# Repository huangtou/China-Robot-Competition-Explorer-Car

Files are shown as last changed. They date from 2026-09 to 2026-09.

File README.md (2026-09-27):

# TianXian · 车型探险机器人

> 主控 STM32F407ZGT6 + MaixCam 视觉，四轮底盘，完成「巡线 → 越障/过桥 → 识别景点数字 → 语音播报 → 返程」全流程的竞赛机器人开源工程。
>
> 包含：STM32 固件（HAL 库 + Keil 工程）、视觉模型与部署脚本、机械结构（SolidWorks）、PCB（立创 EDA）。

<p align="center">
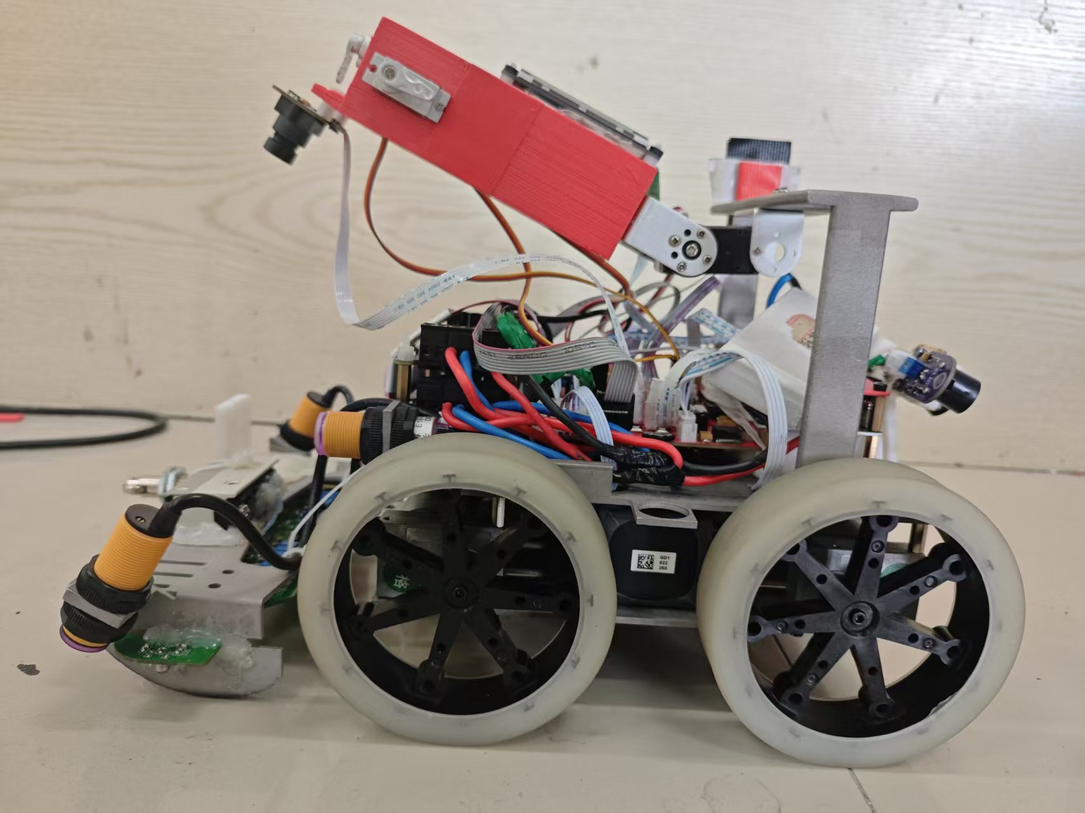
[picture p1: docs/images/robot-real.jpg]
整车实物
  
  <br>
  <em>整车实物</em>
</p>

| 机械结构（3D 预览） | 主控 PCB（3D 预览） |
| :---: | :---: |
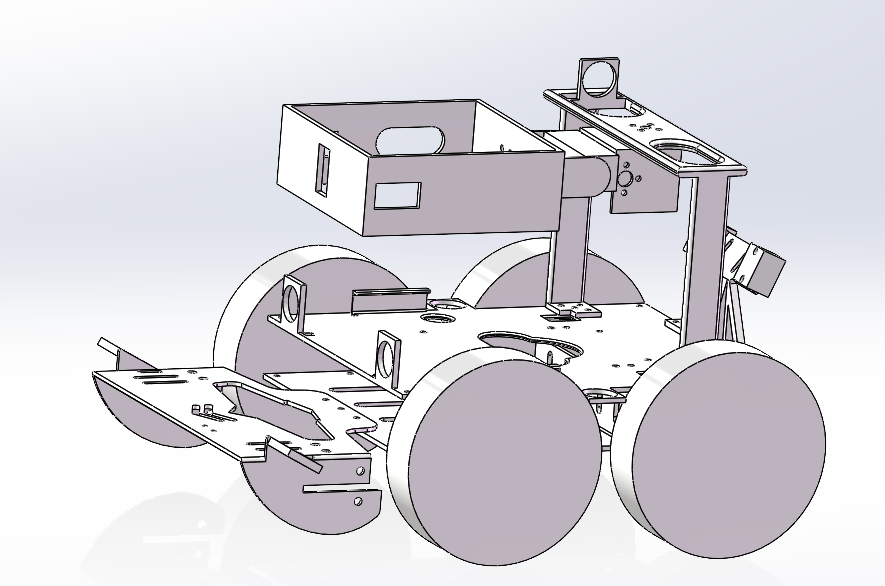
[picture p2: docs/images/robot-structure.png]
机械结构
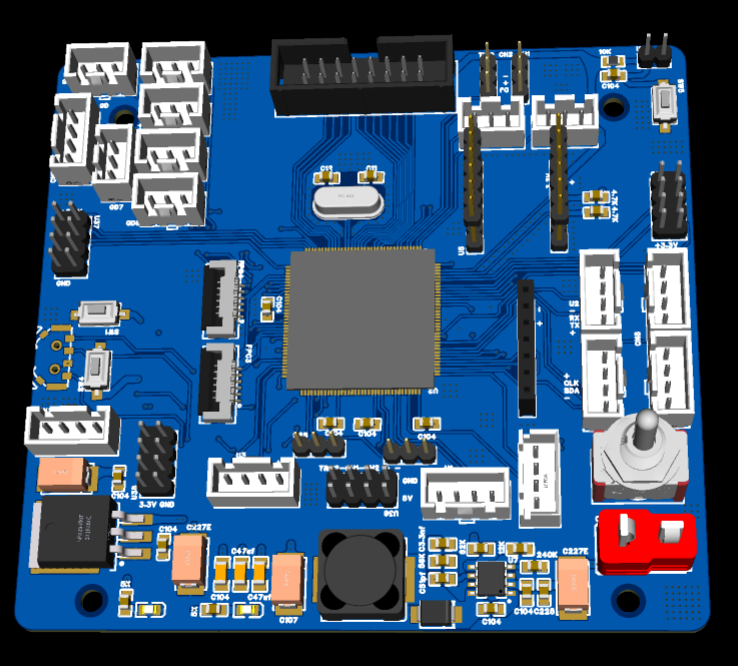
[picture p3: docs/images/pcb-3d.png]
主控 PCB
|  |  |

**[▶ 演示视频（Bilibili，V1）](https://www.bilibili.com/video/BV1UiGg6rEV1/)**

---

## 一、项目简介

机器人以「五岳景点打卡」为任务背景：沿场地循迹行进，途中完成上/下阶梯、过桥、上下平台等动作，用摄像头识别景点编号（1~5），通过语音模块播报「到达东岳泰山 / 西岳华山 / 南岳衡山 / 北岳恒山 / 中岳嵩山」，最后回到起点。

- **主控**：STM32F407ZGT6（LQFP144，168 MHz）
- **底盘**：4 × 带编码器减速电机（四轮独立速度闭环）
- **视觉**：MaixCam 运行 YOLOv5（224×224，5 类），UART 回传识别结果
- **导航**：12 路灰度 + 2 路线性 CCD 巡线，HWT101 陀螺仪航向闭环，光电/激光/微动开关做定位与触发
- **交互**：TJC 串口屏菜单选模式、SYN6288 语音播报、VOFA+ 上位机调参

## 二、功能特性

| 能力 | 实现 |
| --- | --- |
| 巡线 | 12 路灰度 `Huidu_findline` + 2 路线性 CCD `CcdFindLine2`，分段 PID（按速度切换 5 套参数） |
| 运动控制 | 4 路电机速度环 PID（`htim6` 1 ms 中断）+ 编码器里程计 + 陀螺仪角度环 PID |
| 动作原语 | `go / go_enco / go_time / go_GD / go_acc / HWT101_go / HWT101_go_rotate` 等，支持自定义终止回调 |
| 任务编排 | `part1_pro ~ part4_pro` 四段路线，配合 `flagroad_0~4` 岔路标记位 |
| 视觉识别 | MaixCam YOLOv5 数字识别，稳定 4 帧后才发送，超时自动复 0 |
| 语音播报 | SYN6288 合成播报，首次识别结果缓存至 `ZL[5]`，二次经过直接复播 |
| 调试工具 | 串口屏菜单 16 种模式、VOFA+ 实时波形、`keilkill.bat` 清理编译中间产物 |

## 三、目录结构

```
.
├── 代码/stm32代码HAL库/
│   ├── Core/                 # CubeMX 生成的时钟/外设初始化与 main.c
│   ├── Drivers/              # STM32F4 HAL 库、CMSIS
│   ├── Hard-and-Software/    # 本项目全部应用层代码（见下表）
│   ├── MDK-ARM/              # Keil uVision 工程（TianXian.uvprojx）
│   ├── Camera/               # MaixCam 视觉应用与模型
│   │   ├── 2.0-es/           # 早期模型 316024
│   │   ├── 2.2-es/           # 模型 316110
│   │   └── 2.3/              # 推荐版本：2.0-es 逻辑 + 316110 模型
│   ├── TianXian.ioc          # STM32CubeMX 配置（外设/引脚/时钟）
│   └── keilkill.bat          # 清理 Keil 编译中间文件
├── 结构/                      # SolidWorks 零件与装配体（.SLDPRT/.SLDASM/STL）
├── PCB/
│   └── PCB.eprj2             # 立创 EDA 专业版工程
├── docs/images/              # README 用预览图（整车实物、机械结构、PCB 3D 渲染）
└── README.md
```

### 应用层模块（`Hard-and-Software/`）

| 文件 | 职责 |
| --- | --- |
| `sys.c/h` | 全局头文件聚合、`CAR_STRUCT` 车体状态结构体、`Para_Init` 参数初始化 |
| `move.c/h` | 电机 PWM 输出、编码器/速度采集、速度环与角度环 PID |
| `base.c/h` | 运动原语：定距、定时、加速、灰度终止、陀螺仪转向等 |
| `private.c/h` | 任务流程：`Ready / LBridge / to5 / gohome` 等，以及 `part1~4_pro` |
| `Huidu.c/h` | 12 路灰度寻线偏差计算 |
| `CCD.c/h` | 线性 CCD 时序驱动、自动曝光、寻线与 CCD 巡线 PID |
| `HWT101.c/h` | 软件 I²C 读取 HWT101 陀螺仪、角度标定 |
| `Kalman.c/h` | 传感器数据卡尔曼滤波 |
| `GD.c/h` | 光电/激光/微动开关等数字量输入 |
| `HSL.c/h` | 颜色传感器（软件 I²C） |
| `DJ.c/h` | 舵机动作组：身体、摄像头云台、左右手 |
| `myusart.c/h` | printf 重定向、MaixCam 协议解析、SYN6288 语音帧组包 |
| `Serial.c/h` | `Serial.HMI`（串口屏）/ `Serial.Vofa`（VOFA+）格式化输出 |
| `key.c/h` | 按键扫描与运行模式选择 |
| `Timer.c/h` | 定时器中断回调（控制 / 采集 / 计时） |

## 四、硬件与引脚分配

| 外设 | 引脚 / 资源 | 说明 |
| --- | --- | --- |
| 电机 PWM | TIM4 CH1~CH4（轮 1/2）、TIM5 CH1~CH4（轮 3/4） | 每轮两路 PWM 实现正反转 |
| 编码器 | TIM1 / TIM2 / TIM3 / TIM8（编码器模式） | 4 路 AB 相 |
| 舵机 | TIM9 CH1/CH2（身体、云台）、TIM12 CH1/CH2（右手、左手） | 50 Hz |
| 灰度传感器 | ADC3 + DMA2_Stream0，12 通道扫描 | `AD_value[12]` |
| 线性 CCD ×2 | CCD1：CLK=PG0、SI=PG1；CCD2：CLK=PE7、SI=PE8；ADC2 CH4/CH5 | TSL1401 类 128 像素 |
| 陀螺仪 HWT101 | 软件 I²C：SDA=PE0、SCL=PE1 | 航向角闭环 |
| 颜色传感器 HSL | SDA=PD2、SCL=PD3 | |
| 光电开关 | GD1=PA6、GD2=PA7、GD5=PC4、GD6=PC5、GD7=PB0、GD8=PB1 | 定位/计数 |
| 激光对射 | JG1=PE2、JG2=PE3 | |
| 微动开关 | QC1=PC13 | 到位检测 |
| 按键 ×4 | KEY_LEFT=PD8、KEY_MID=PD9、KEY_RIGHT=PD10、KEY1=PD11 | 模式选择 |
| USART1 | PA9/PA10 | TJC 串口屏 + `printf` 重定向 |
| USART2 | PD5/PD6 | MaixCam 数据接收（RX）+ VOFA+（TX），115200 |
| USART3 | PB10/PB11 | SYN6288 语音合成模块 |
| 定时器 | TIM6 控制（1 ms）、TIM7 采集（1 ms）、TIM10 计时 | |

## 五、编译与烧录

1. **环境**
   - Keil MDK-ARM **V5.32** 及以上，安装 STM32F4 器件支持包
   - STM32CubeMX（本项目基于 `STM32Cube FW_F4 V1.28.1` 生成）
2. 打开 `代码/stm32代码HAL库/MDK-ARM/TianXian.uvprojx`，编译（Target: TianXian）后通过 ST-Link 下载。
3. 修改外设配置时用 CubeMX 打开 `TianXian.ioc` 重新生成即可（用户代码写在 `USER CODE BEGIN/END` 之间，不会被覆盖）。
4. 提交仓库前建议运行 `keilkill.bat` 清理 `Objects/`、`Listings/` 等中间文件。

## 六、视觉模型部署（MaixCam）

1. 将 `Camera/2.3/` 下 `app.yaml`、`main.py`、`app.png`、`model_316110.mud`（或 `.cvimodel`）、`report.json` 打包，在 [MaixHub](https://maixhub.com) 部署或直接用 MaixVision 安装到设备。
2. 模型：YOLOv5n 级检测模型，输入 224×224，5 类，验证集准确率 0.982（`report.json`）。
3. **通信协议**：串口 `/dev/ttyS0`，115200，帧格式 `0xAA + ASCII('0'~'5') + 0xBB`
   - `'1'~'5'` 对应 东岳泰山 / 西岳华山 / 南岳衡山 / 北岳恒山 / 中岳嵩山（注意模型类序为 `3,4,5,1,2`，代码已做映射）
   - `'0'` 表示未识别到目标
   - 连续 4 帧同一结果才发送，之后每 10 帧补发一次；连续 60 帧无目标则发送 `'0'`

> 需要重新训练模型时，在 MaixHub 上传标注数据集（5 类）即可，导出后替换 `model_*.mud` 并同步 `CLASS_TO_NUMBER`。

## 七、运行与调试

1. 上电后串口屏显示模式选择界面：`左/右` 键切换编号（1~16），`中` 键确认，`KEY1` 直接跳到模式 5。
2. 常用模式（`main.c` 中 `Function_Value`）：

| 模式 | 功能 |
| --- | --- |
| 1 | 完整跑图（part1→part4 执行两轮） |
| 2 | 单轮跑图 |
| 3 | 灰度 / CCD 巡线调试 |
| 4 | HWT101 陀螺仪 + 光电调试 |
| 5 | 综合调试：串口屏显示 + 摄像头读取 |
| 6 | 摄像头识别 + 语音播报测试 |
| 8 | 直行测试 |

3. 调参入口集中在 `sys.c` 的 `Para_Init()`（灰度阈值 `ADW[]`、多套巡线 PID、速度/角度 PID）与 `move.c` 的 PID 实现；实时波形用 VOFA+ 打开 USART2 对应串口查看。

## 八、机械与硬件

| 机械结构 | 主控 PCB |
| :---: | :---: |
| 机械结构 | 主控 PCB |

- `结构/`：`装配体2.SLDASM` 为整机装配，其余为车身、电机底盘、舵机支架、轮子、CCD 支架、喇叭等零件，另附 `升级版ccd.STL` 可直接 3D 打印。
- `PCB/PCB.eprj2`：立创 EDA 专业版工程，直接导入即可查看/打样。

## 九、演示视频

- **V1 完整流程演示**：<https://www.bilibili.com/video/BV1UiGg6rEV1/> ｜ BV 号 `BV1UiGg6rEV1`

## 十、开源协议

本项目采用 **MIT License**。第三方组件遵循各自许可证：

- `Drivers/` 下 STM32 HAL / CMSIS 遵循 ST 官方许可；
- `Camera/` 下模型与脚本由 MaixHub 生成，遵循 Sipeed / MaixHub 相关条款。

## 十一、致谢

- STMicroelectronics：STM32CubeMX / HAL 库
- Sipeed MaixHub / MaixCam：模型训练与部署平台
- 维特智能 HWT101、SYN6288 语音模块、淘晶驰 TJC 串口屏、VOFA+ 上位机

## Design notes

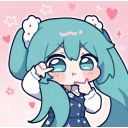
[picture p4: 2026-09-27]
代码/stm32代码HAL库/Camera/2.2-es/app.png

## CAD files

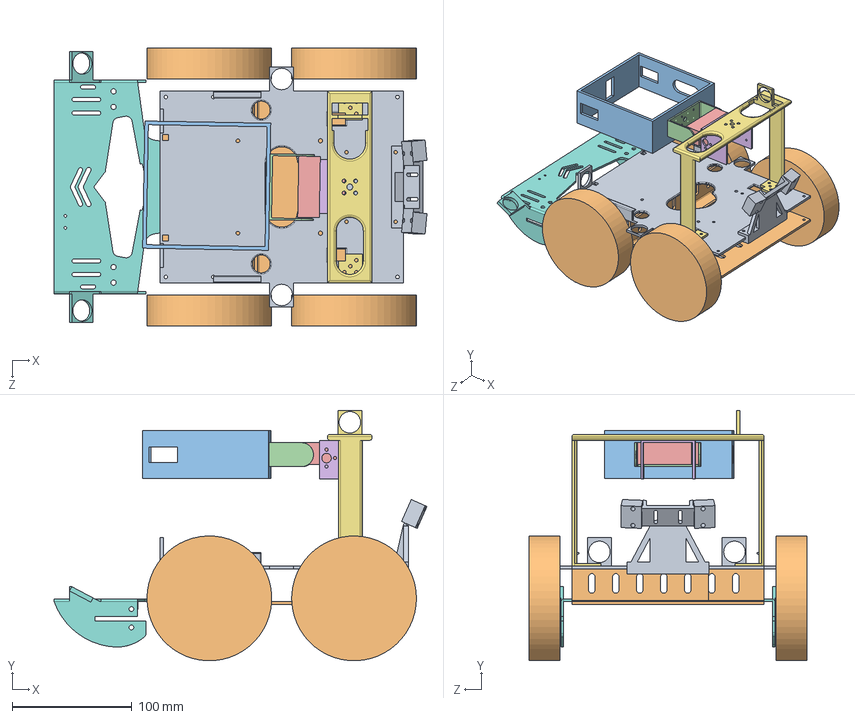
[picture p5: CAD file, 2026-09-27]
结构/装配体2.SLDASM
310.9 x 208.7 x 232.0 mm
xin电机低盘
xin电机底盘上盖111
固定灰度112
xin电机底盘上盖架子
舵机支架下
舵机25
舵机支架动
身体新喇叭
轮子大 x 4
升级版ccd

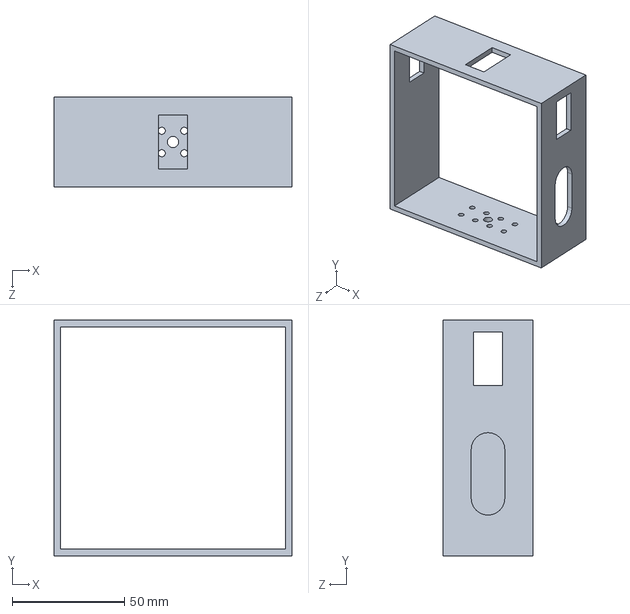
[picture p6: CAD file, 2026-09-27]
结构/身体新喇叭.SLDPRT
106.0 x 105.0 x 40.0 mm

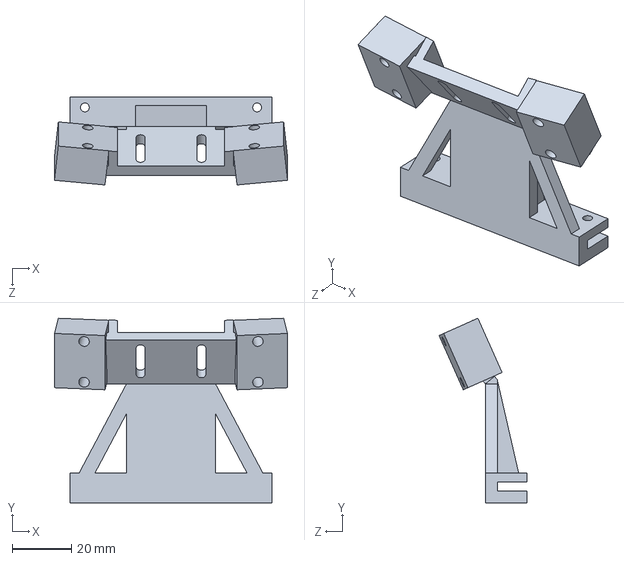
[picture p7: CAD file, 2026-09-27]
结构/升级版ccd.SLDPRT
78.4 x 62.1 x 29.6 mm

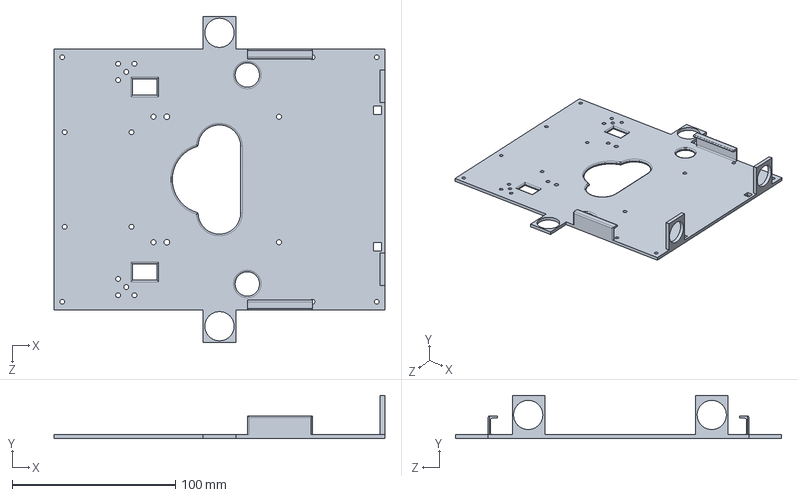
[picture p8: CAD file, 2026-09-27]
结构/xin电机底盘上盖111.SLDPRT
203.0 x 26.5 x 200.0 mm

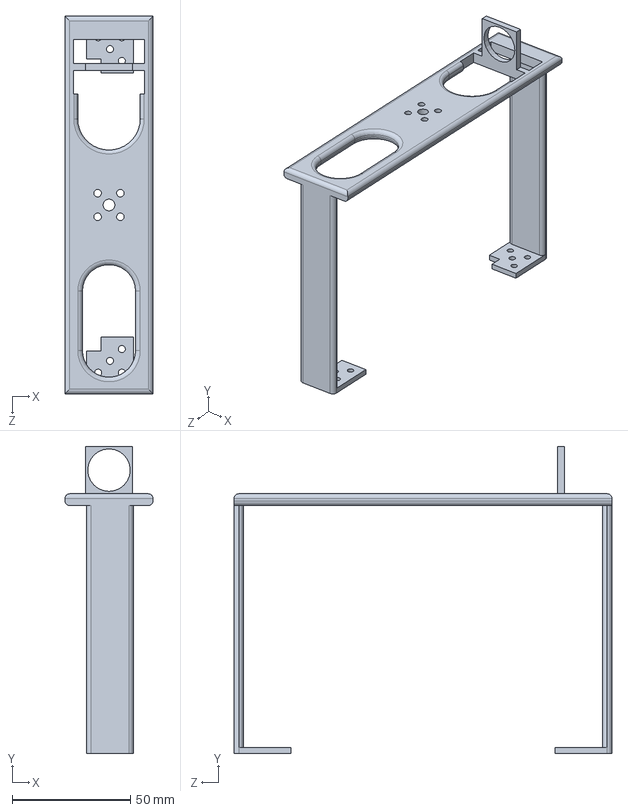
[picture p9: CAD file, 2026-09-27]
结构/xin电机底盘上盖架子.SLDPRT
37.3 x 130.0 x 160.0 mm

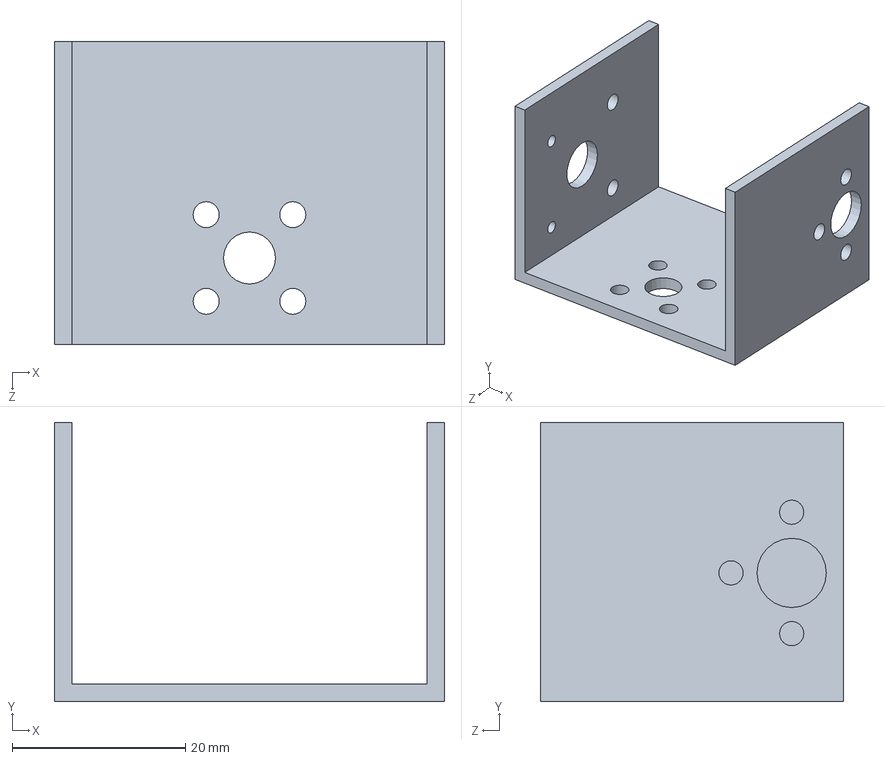
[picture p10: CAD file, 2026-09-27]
结构/舵机支架下.SLDPRT
45.0 x 32.2 x 35.0 mm

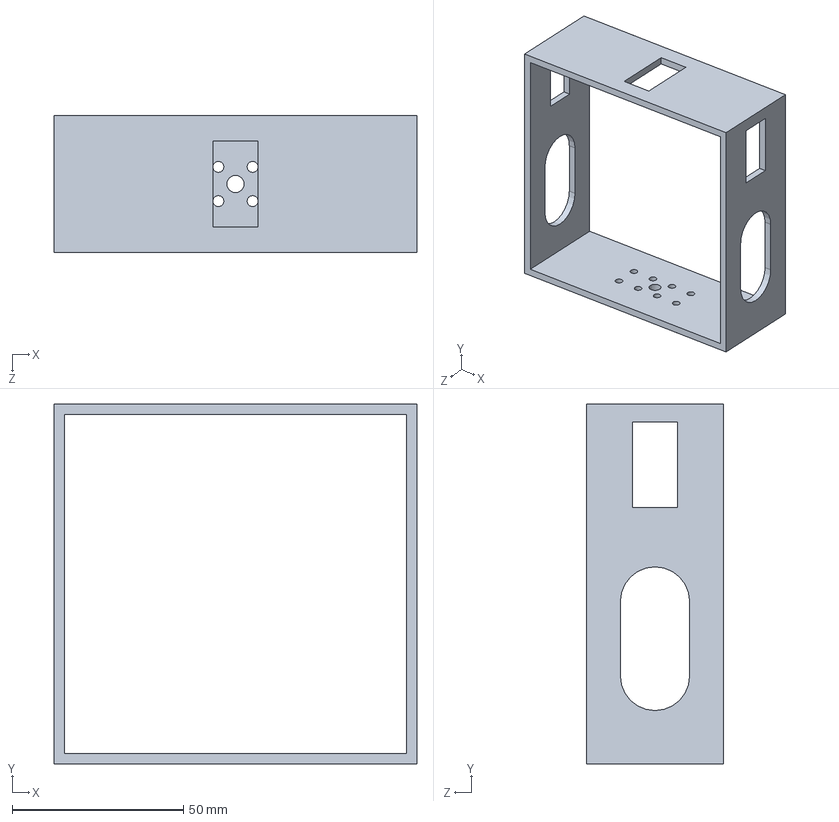
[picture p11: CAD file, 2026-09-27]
结构/身体.SLDPRT
106.0 x 105.0 x 40.0 mm

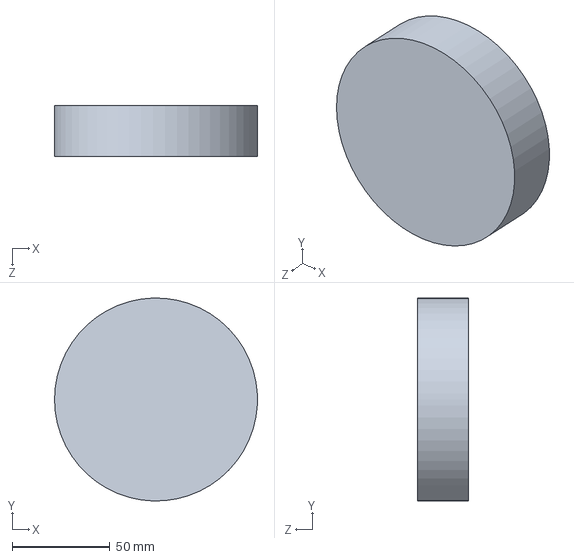
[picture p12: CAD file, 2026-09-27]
结构/轮子大.SLDPRT
104.0 x 104.0 x 26.0 mm

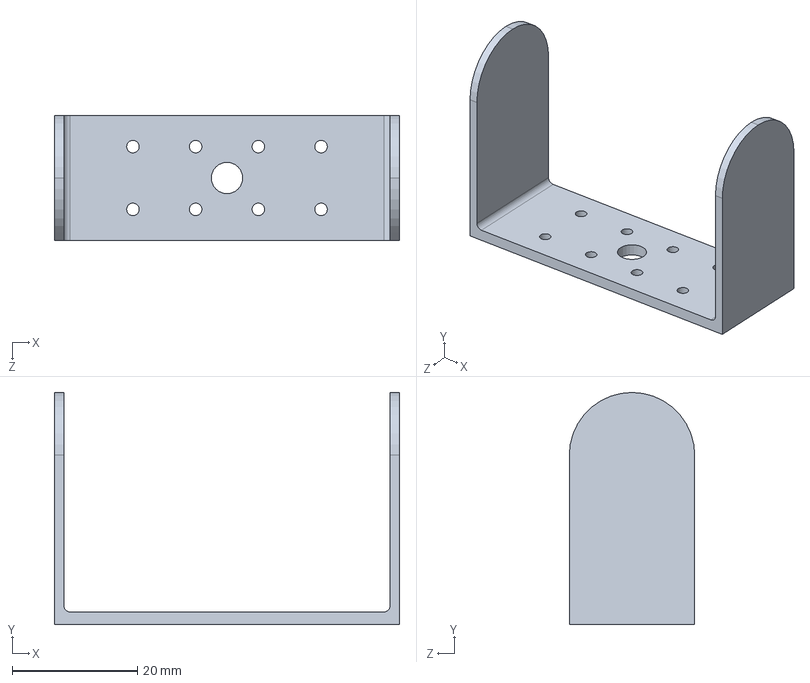
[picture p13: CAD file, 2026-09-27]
结构/舵机支架动.SLDPRT
55.0 x 37.0 x 20.0 mm

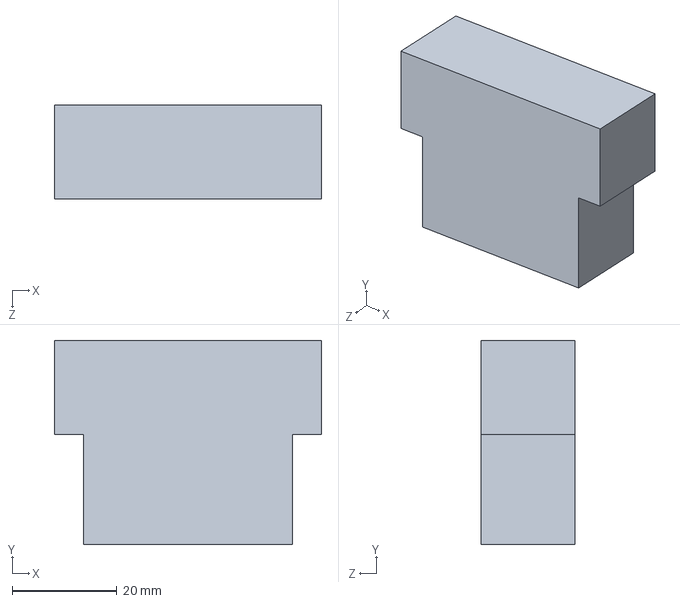
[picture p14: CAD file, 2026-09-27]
结构/舵机25.SLDPRT
51.0 x 39.0 x 18.0 mm

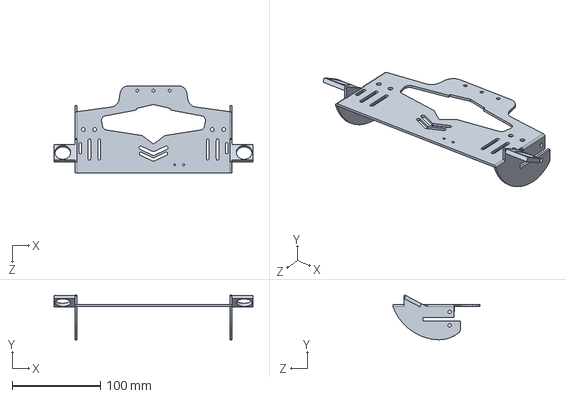
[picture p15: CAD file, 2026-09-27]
结构/固定灰度112.SLDPRT
226.0 x 50.7 x 99.3 mm

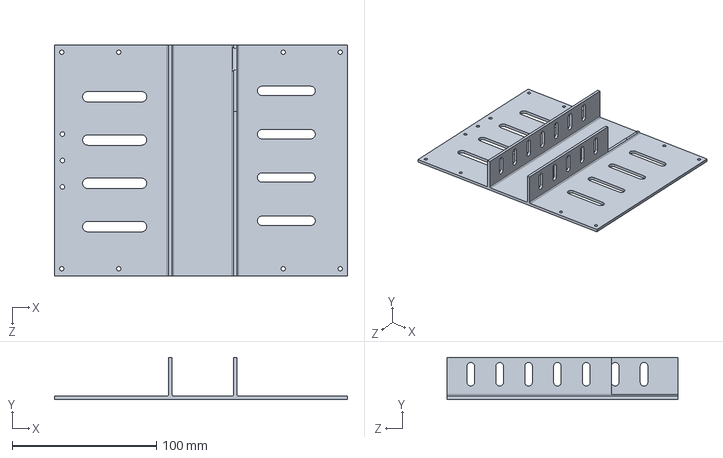
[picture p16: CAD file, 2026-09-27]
结构/xin电机低盘.SLDPRT
203.0 x 29.4 x 160.0 mm

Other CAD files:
结构/xin升级版ccd.SLDPRT
结构/升级版ccd.STL

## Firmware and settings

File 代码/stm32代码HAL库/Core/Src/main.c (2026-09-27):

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
/* Includes ------------------------------------------------------------------*/
#include "main.h"
#include "adc.h"
#include "dma.h"
#include "tim.h"
#include "usart.h"
#include "gpio.h"

/* USER CODE BEGIN PTD */

	CAR_STRUCT car;
	Kalman     kfp;
	volatile PID pid_1;
	volatile PID pid_2;
	volatile PID pid_3;
	volatile PID pid_4;
	
	volatile PID pid_F;//    
	volatile PID pid_A;//
	volatile PID pid_R;// 
	
//	volatile float I_limit=100;					
	volatile int A_limit=180;						
	volatile int P_V_limit=900;
	
	
	volatile int velocity[5]={0};
	volatile int32_t encoder[5]={0};
	uint16_t AD_value[12];
	uint16_t AD_data[12];
	unsigned char HSL_value[3];
	u8 Function_Value=0;
	int cou=0;
	uint32_t CHANNEL_CCD;
	int8_t flag6times;
	int carrr;

/* USER CODE END PTD */

/* USER CODE BEGIN PM */
int count;
/* USER CODE END PM */


void SystemClock_Config(void);
/**
  * @brief  The application entry point.
  * @retval int
  */
int main(void)
{

  /* MCU Configuration--------------------------------------------------------*/

  /* Reset of all peripherals, Initializes the Flash interface and the Systick. */
  HAL_Init();

  /* Configure the system clock */
  SystemClock_Config();

  /* Initialize all configured peripherals */
  MX_GPIO_Init();
  MX_DMA_Init();
  MX_TIM4_Init();
  MX_TIM5_Init();
  MX_ADC3_Init();
  MX_TIM1_Init();
  MX_TIM2_Init();
  MX_TIM3_Init();
  MX_TIM8_Init();
  MX_TIM9_Init();
  MX_TIM12_Init();
  MX_TIM6_Init();
  MX_TIM7_Init();
  MX_TIM10_Init();
  MX_ADC2_Init();
  MX_USART1_UART_Init();
  MX_USART3_UART_Init();
  MX_USART2_UART_Init();
  /* USER CODE BEGIN 2 */
  
	HAL_TIM_Base_Start_IT(&htim7);//read
	HAL_ADC_Start_DMA(&hadc3,(uint32_t*)AD_value,12);
	move_init();
	Para_Init();
	Kalman_Init();
	Dj_all_Init();
	printf("\x01\xff\xff\xff");
	printf("t0.txt=\"no\"\xFF\xFF\xFF");
	printf("t13.txt=\"NULL\"\xFF\xFF\xFF");
//	HAL_UART_Receive_IT(&huart2, &usart2_dataRcvd, 1);
	HAL_Delay(50);

  /* USER CODE END 2 */

  /* Infinite loop */
  /* USER CODE BEGIN WHILE */

//	SYN_FrameInfo(0, "[v16][t5]?  ");
//	HAL_TIM_Base_Start_IT(&htim6);
   Function_Value = Function_Mode();
//	car.state = 1;
  HAL_Delay(50);
   
//	car.Target=250;
//  HWT101_Calibrate();
//  HWT101_go(0,100,NULL);
//    go((1<<0)|(1<<1),100,0,0,NULL);******************
//	move_control(800,0,0,0);
//	go_time(100000,-100,1,0,NULL);
//	go_enco(50,100,0,0,NULL);
//	HWT101_Calibrate();
//	HWT101_go(0,0,NULL);
//	car.Target=-100;
//	car.state=100;
//while(1)	
//{
//	HAL_TIM_Base_Stop_IT(&htim6);
//	move_control(0,0,0,0);
//	HAL_Delay(5000);
//	HAL_TIM_Base_Start_IT(&htim6);
//	HAL_Delay(10000);
//}
  
  while (1)
  {
	  if(Function_Value==5)		//ALL      
		{
			DJ_QQB();
//			DJ_down();
			USART2_StartRead();
			HAL_TIM_Base_Stop_IT(&htim7);
			Display();
		}
		if(Function_Value==1)
		{
			Ready();
			part1_pro();
			part2_pro();
			part3_pro();
			part4_pro();
			Ready();
			part1_pro();
			part2_pro();
			part3_pro();
			part4_pro();

			
			stop(1);
			while(1);
		}
		if(Function_Value==2)
		{
			
			Ready();
			
			
			part1_pro();
			part2_pro();
			part3_pro();
			part4_pro();
			stop(1);
			while(1);
		}
		
		if(Function_Value==3)	//huidu_PID_test//zuo_you_test
		{
			Ready();
			
			stop(20);


			
//			DJ_QQB();
////			DJ_down();
//			stop(500);

////////////////////////////////////////////			
//			qi_bu();
//			car.Target_dis = 100;
//			go_acc(80,90,110,1,0,my_enco);
//			
////			car.Av = 8.5;	//change huidu_av
//			
//			go_enco(400,110,1,0,NULL);
//			
//			car.Target_dis = 50;
//			go_acc(80,110,90,1,0,my_enco);
////////////////////////////////////////////
//			
////			car.Target_dis = 55;
////			go_acc(50,85,110,0,1,my_enco);
////			go_GD(1,110,0,1,NULL);						//到阶梯
////			
////			go_enco(80,80,0,0,NULL);		//过阶梯/////////////////////////////////////////////////
////			go_enco(35,90,0,0,NULL);		//过阶梯/////////////////////////////////////////////////

////			go_enco(100,110,0,-1,NULL);		//到直线

////			go_acc(100,110,300,0,0,my_huidu1011);
////			go_enco(40,300,0,0,NULL);					//测  场地实际距离170cm，去掉减速距离，走的距离要比170cm少一点
////			go_acc(100,300,110,0,-1,my_huidu1011);

////			
////			go_enco(70,110,0,-1,NULL);		//左巡进岔路///////////////////////////////////////////

////			car.Target_dis = 30;
////			go_acc(100,110,250,0,0,my_enco);

////			car.Target_dis = 90;
////			go_acc(100,250,85,0,0,my_enco);
////			
////			go_enco(40,60,0,0,my_qc1);
			
			while(1){}
		}
		
		if(Function_Value==4)		  //test HWT101_GD
		{
			DJ_down();
			stop(500);
			
			HWT101_Calibrate();
			HWT101_GD(0,100,0,0,NULL);

			while(1){}
		}
		
		if(Function_Value==8)		  //test HWT101_GD
		{
			Ready();
			go_acc(100,-90,-100,0,0,NULL);
			
			while(1){}
		}
		
		
		if(Function_Value==6)		  
		{		
			

			DJ_camera_look();
			stop(500);
				
			
	
//			TIM9->CCR1=250;
//			stop(200);
//			TIM9->CCR1=450;
//			stop(200);
//			TIM9->CCR1=250;
			
			while(1)
			{
				USART2_StartRead();
				
				stop_read(TIME_READ);
				
				USART2_StopRead();
				SYN_ZL(ZL_ID);
				
				HAL_Delay(5000);
			}
		}



    /* USER CODE END WHILE */

    /* USER CODE BEGIN 3 */
  }
  /* USER CODE END 3 */
}

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
/* USER CODE BEGIN 4 */

//			  Read_128(ADC_CHANNEL_4);
//			  Gap_Avr(Pixel, 4);
//			  Aver128(Pixel,0,31);
//			  for (int i=0;i<32;i++)
//			  {
//				  printf("%d,%d,%f\n",Pixel[i],car.delay_time,car.minav2);
//			  }
//			  for (int i=0;i<20;i++)
//			  {	
//				  printf("%d,%d,%f\n",225,car.delay_time,car.minav2);
//			  
//			  }
//			  auto_Exposure();
//			  HAL_Delay(car.delay_time);

/* USER CODE END 4 */
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


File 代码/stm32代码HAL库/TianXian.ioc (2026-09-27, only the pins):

Mcu.UserName=STM32F407ZGTx
PA0-WKUP.Signal=S_TIM5_CH1
PA1.Signal=S_TIM5_CH2
PA10.Signal=USART1_RX
PA13.Signal=SYS_JTMS-SWDIO
PA14.Signal=SYS_JTCK-SWCLK
PA15.Signal=S_TIM2_CH1_ETR
PA2.Signal=S_TIM5_CH3
PA3.Signal=S_TIM5_CH4
PA4.Signal=ADCx_IN4
PA5.Signal=ADCx_IN5
PA6.GPIO_Label=GD1
PA6.Signal=GPIO_Input
PA7.GPIO_Label=GD2
PA7.Signal=GPIO_Input
PA9.Signal=USART1_TX
PB0.GPIO_Label=GD7
PB0.Signal=GPIO_Input
PB1.GPIO_Label=GD8
PB1.Signal=GPIO_Input
PB10.Signal=USART3_TX
PB11.Signal=USART3_RX
PB14.Signal=S_TIM12_CH1
PB15.Signal=S_TIM12_CH2
PB3.Signal=S_TIM2_CH2
PB4.Signal=S_TIM3_CH1
PB5.Signal=S_TIM3_CH2
PB6.Signal=S_TIM4_CH1
PB7.Signal=S_TIM4_CH2
PB8.Signal=S_TIM4_CH3
PB9.Signal=S_TIM4_CH4
PC0.Signal=ADCx_IN10
PC1.Signal=ADCx_IN11
PC13-ANTI_TAMP.GPIO_Label=QC1
PC13-ANTI_TAMP.Signal=GPIO_Input
PC14-OSC32_IN.Signal=RCC_OSC32_IN
PC15-OSC32_OUT.Signal=RCC_OSC32_OUT
PC2.Signal=ADCx_IN12
PC3.Signal=ADCx_IN13
PC4.GPIO_Label=GD5
PC4.Signal=GPIO_Input
PC5.GPIO_Label=GD6
PC5.Signal=GPIO_Input
PC6.Signal=S_TIM8_CH1
PC7.Signal=S_TIM8_CH2
PD10.GPIO_Label=KEY_RIGHT
PD10.Signal=GPIO_Input
PD11.GPIO_Label=KEY1
PD11.Signal=GPIO_Input
PD2.GPIO_Label=HSL_SDA
PD2.Signal=GPIO_Output
PD3.GPIO_Label=HSL_CLK
PD3.Signal=GPIO_Output
PD5.Signal=USART2_TX
PD6.Signal=USART2_RX
PD8.GPIO_Label=KEY_LEFT
PD8.Signal=GPIO_Input
PD9.GPIO_Label=KEY_MID
PD9.Signal=GPIO_Input
PE0.GPIO_Label=TLY_SDA
PE0.Signal=GPIO_Output
PE1.GPIO_Label=TLY_SCL
PE1.Signal=GPIO_Output
PE11.Signal=S_TIM1_CH2
PE2.GPIO_Label=JG1
PE2.Signal=GPIO_Input
PE3.GPIO_Label=JG2
PE3.Signal=GPIO_Input
PE5.Signal=S_TIM9_CH1
PE6.Signal=S_TIM9_CH2
PE7.GPIO_Label=CCD2_CLK
PE7.Signal=GPIO_Output
PE8.GPIO_Label=CCD2_SI
PE8.Signal=GPIO_Output
PE9.Signal=S_TIM1_CH1
PF10.Signal=ADC3_IN8
PF3.Signal=ADC3_IN9
PF4.Signal=ADC3_IN14
PF5.Signal=ADC3_IN15
PF6.Signal=ADC3_IN4
PF7.Signal=ADC3_IN5
PF8.Signal=ADC3_IN6
PF9.Signal=ADC3_IN7
PG0.GPIO_Label=CCD1_CLK
PG0.Signal=GPIO_Output
PG1.GPIO_Label=CCD1_SI
PG1.Signal=GPIO_Output
PH0-OSC_IN.Signal=RCC_OSC_IN
PH1-OSC_OUT.Signal=RCC_OSC_OUT

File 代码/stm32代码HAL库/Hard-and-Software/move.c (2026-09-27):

#include "sys.h"

extern volatile int P_V_limit;

extern volatile int A_limit;

float mabs(float a)		//函数功能：绝对值计算
{
	if(a<=0) return -a;
 	else  return a;
}

void limit(float* integral,float limitation)	//函数功能：积分限幅
{
	if(*integral>=mabs(limitation)) *integral=mabs(limitation);
 	else if(*integral<=-mabs(limitation)) *integral=-mabs(limitation);
}

void move_init(void)	//函数功能：小车移动初始化
{
	//开启编码器定时器（读取编码器信号、计算电机转速/位置）
	HAL_TIM_Encoder_Start(&htim1, TIM_CHANNEL_ALL);	
	HAL_TIM_Encoder_Start(&htim2, TIM_CHANNEL_ALL);
	HAL_TIM_Encoder_Start(&htim3, TIM_CHANNEL_ALL);
	HAL_TIM_Encoder_Start(&htim8, TIM_CHANNEL_ALL);
	//开启许多PWM（输出PWM波，驱动执行器）
	HAL_TIM_PWM_Start(&htim4,TIM_CHANNEL_1);				//使能2号电机PWM
	HAL_TIM_PWM_Start(&htim4,TIM_CHANNEL_2);				//使能2号电机PWM（正转）
	HAL_TIM_PWM_Start(&htim4,TIM_CHANNEL_3);				//使能1号电机PWM（正转）
	HAL_TIM_PWM_Start(&htim4,TIM_CHANNEL_4);				//使能1号电机PWM

	HAL_TIM_PWM_Start(&htim5,TIM_CHANNEL_1);				//使能4号电机PWM
	HAL_TIM_PWM_Start(&htim5,TIM_CHANNEL_2);				//使能4号电机PWM（正转）
	HAL_TIM_PWM_Start(&htim5,TIM_CHANNEL_3);				//使能3号电机PWM（正转）
	HAL_TIM_PWM_Start(&htim5,TIM_CHANNEL_4);				//使能3号电机PWM
	
	HAL_TIM_PWM_Start(&htim9,TIM_CHANNEL_1);				
	HAL_TIM_PWM_Start(&htim9,TIM_CHANNEL_2);
	HAL_TIM_PWM_Start(&htim12,TIM_CHANNEL_1);
	HAL_TIM_PWM_Start(&htim12,TIM_CHANNEL_2);

}


void move_control(int wheel_1,int wheel_2,int wheel_3,int wheel_4)	//函数功能：控制电机正反转
{
	for(uint8_t i=0;i<4;i++)
	{
		switch(i)
		{
			case 0: if(wheel_1>=900)wheel_1=900;else if(wheel_1<-900)wheel_1=-900;	//从后往前看：1号电机 对应 左前方轮子
					if(wheel_1>=0) {TIM4->CCR3=wheel_1;  TIM4->CCR4=0;        break;}
					else		   {TIM4->CCR3=0;        TIM4->CCR4=-wheel_1; break;}
			case 1:if(wheel_2>=900)wheel_2=900;else if(wheel_2<-900)wheel_2=-900;		//从后往前看：2号电机 对应 右前方轮子
					if(wheel_2>=0) {TIM4->CCR2=wheel_2;  TIM4->CCR1=0;        break;}
					else		   {TIM4->CCR2=0;        TIM4->CCR1=-wheel_2; break;}
			case 2: if(wheel_3>=900)wheel_3=900;else if(wheel_3<-900)wheel_3=-900;	//从后往前看：3号电机 对应 左后方轮子
					if(wheel_3>=0) {TIM5->CCR3=wheel_3;  TIM5->CCR4=0;break;}
					else		   {TIM5->CCR3=0;        TIM5->CCR4=-wheel_3; break;}
			case 3: if(wheel_4>=900)wheel_4=900;else if(wheel_4<-900)wheel_4=-900;	//从后往前看：4号电机 对应 右后方轮子
					if(wheel_4>=0) {TIM5->CCR2=wheel_4;  TIM5->CCR1=0;        break;}
					else		   {TIM5->CCR2=0;        TIM5->CCR1=-wheel_4; break;}
		}
	}
}

void move_velocity(void)
{
	velocity[1]=(short)TIM1->CNT;
	TIM1->CNT=0;
	velocity[2]=-(short)TIM2->CNT;
	TIM2->CNT=0;
	velocity[3]=(short)TIM8->CNT;
	TIM8->CNT=0;
	velocity[4]=-(short)TIM3->CNT;
	TIM3->CNT=0;
}

void move_encoder(void)	//函数功能：读取编码器每20ms的计数变化量//读取每个编码器的总脉冲数 后参与Timer.c中292行 平均总脉冲数的计算
{
	encoder[1]+=(short)TIM1->CNT;		//累计的是编码器1从启动到当前的总脉冲数//后续通过”总脉冲数 ÷ 分辨率 = 总圈数”以及轮径、减速比等参数可转换为实际移动距离（如 go_enco 函数中的 dis*2700/50 就是脉冲数到距离的转换系数）
	encoder[2]+=-(short)TIM2->CNT;	//编码器安装/接线导致原始计数方向相反，所以要递减
	encoder[3]+=(short)TIM8->CNT;		
	encoder[4]+=-(short)TIM3->CNT;	
}

void PID_Init(volatile PID* pid, float kp, float ki, float kd)	//函数功能：给PID结构体快速赋值
{
	pid->kp=kp;
	pid->ki=ki;
	pid->kd=kd;
	pid->error=0;
	pid->lasterror=0;
	pid->preerror=0;
	pid->integral=0;
	pid->output=0;
}

//PID*pid:PID数据类型		pid指针-地址	填入&pid_A
//target:目标
//actual:实际
void PID_calc_A(volatile PID*pid, float target, float actual)	//函数功能：转角度PID
{
	//计算error并限幅
	pid->error=target-actual;
	if(pid->error>=180) pid->error=pid->error-360;
	else if(pid->error<=-180) pid->error=pid->error+360;
	//计算output并限幅
	if(pid->error<=1.0f&&pid->error>=-1.0f) pid->output=0;
	else 
	{
		pid->output=pid->kp*(pid->error)+pid->kd*(pid->error-pid->lasterror);
		pid->lasterror=pid->error;
	}
	limit((float*)&pid->output,A_limit);
}

void PID_calc_V(volatile PID*pid, float target, float actual)	//函数功能：调速PID，计算output//PID结构体指针，目标速度，实际速度
{
	pid->error=target-actual;
	
	pid->output+=pid->kp*(pid->error-pid->lasterror)+pid->ki*(pid->error)+pid->kd*(pid->error-2*pid->lasterror+pid->preerror);//增量式PID
	
	pid->preerror=pid->lasterror;
	pid->lasterror=pid->error;
	limit((float*)&pid->output,P_V_limit);											//积分，限幅
}

void PID_change(int speed)	//函数功能：根据不同的速度，自动适配PID
{
	if(speed<0)
		speed=-speed;
	if(speed<=85)		//专门左右巡线的PID
	{
		car.huidu_P = car.huidu_P1;
		car.huidu_D = car.huidu_D1;
	}
	if(speed>85 && speed<=110)	
	{
		car.huidu_P = car.huidu_P2;
		car.huidu_D =car.huidu_D2;				
	}
	else if(speed>110 && speed<=180)	
	{
		car.huidu_P = car.huidu_P3;
		car.huidu_D =car.huidu_D3;				
	}
	else if(speed>180 && speed<280)
	{
		car.huidu_P = car.huidu_P4;
		car.huidu_D = car.huidu_D4;		
	}
	else if(speed>=280)
	{
		car.huidu_P = car.huidu_P5;
		car.huidu_D = car.huidu_D5;		
	}
}

void huidu_ccd_pid(void)	//灰度巡线，CCD巡线的PID
{
	if(car.Direct==0)//向前走,用灰度循线
	{
		car.ADC_value = Huidu_findline(AD_data,car.Line_Search);//灰度找线函数（这个函数的功能就是把白线位置，即对应的灰度编号找出来）//形参：灰度值，左中右巡，car.ADC_value实际白线位置对应的灰度编号
		if(car.ADC_value>=0&&car.ADC_value<=11.001f)						//如果找到线了
		{
			PID_change(car.Target);																//根据速度改变PID大小的函数//形参：目标速度
			car.Error=car.Av - car.ADC_value;											//误差 = 白线目标位置-白线实际位置
			car.Pout=car.huidu_P*car.Error;												//P
			car.Dout=car.huidu_D*(car.Error-car.Last_Error);			//D
			car.Last_Error=car.Error;
			car.OUT=car.Pout+car.Dout;														//算输出值
			
		//防止超控//可修改
			if(car.OUT>0.8f)
				car.OUT=0.8f;
			else if(car.OUT<-0.8f)
				car.OUT=-0.8f;;
		}
		else
		{
			car.OUT=0;
		}
	}
	else if(car.Direct==-1)//向后走&&即用后面的CCD//与速度赋值无关！！！！
	{
		if(car.ccd_use>2)
			if(car.find!=-1.0)//入果找到了线，再PID
				PIDCCD(car.find,car.CCD_P1,car.CCD_D1);//模式2
	}
	else //向前走&&即用前面的CCD//与速度赋值无关！！！！
	{
		if(car.ccd_use>2)
			if(car.find!=-1)//入果找到了线，再PID
				PIDCCD(car.find,car.CCD_P1,car.CCD_D1);
	}
}

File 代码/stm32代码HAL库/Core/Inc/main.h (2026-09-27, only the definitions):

#define JG1_Pin GPIO_PIN_2
#define JG1_GPIO_Port GPIOE
#define JG2_Pin GPIO_PIN_3
#define JG2_GPIO_Port GPIOE
#define QC1_Pin GPIO_PIN_13
#define QC1_GPIO_Port GPIOC
#define GD1_Pin GPIO_PIN_6
#define GD1_GPIO_Port GPIOA
#define GD2_Pin GPIO_PIN_7
#define GD2_GPIO_Port GPIOA
#define GD5_Pin GPIO_PIN_4
#define GD5_GPIO_Port GPIOC
#define GD6_Pin GPIO_PIN_5
#define GD6_GPIO_Port GPIOC
#define GD7_Pin GPIO_PIN_0
#define GD7_GPIO_Port GPIOB
#define GD8_Pin GPIO_PIN_1
#define GD8_GPIO_Port GPIOB
#define CCD1_CLK_Pin GPIO_PIN_0
#define CCD1_CLK_GPIO_Port GPIOG
#define CCD1_SI_Pin GPIO_PIN_1
#define CCD1_SI_GPIO_Port GPIOG
#define CCD2_CLK_Pin GPIO_PIN_7
#define CCD2_CLK_GPIO_Port GPIOE
#define CCD2_SI_Pin GPIO_PIN_8
#define CCD2_SI_GPIO_Port GPIOE
#define KEY_LEFT_Pin GPIO_PIN_8
#define KEY_LEFT_GPIO_Port GPIOD
#define KEY_MID_Pin GPIO_PIN_9
#define KEY_MID_GPIO_Port GPIOD
#define KEY_RIGHT_Pin GPIO_PIN_10
#define KEY_RIGHT_GPIO_Port GPIOD
#define KEY1_Pin GPIO_PIN_11
#define KEY1_GPIO_Port GPIOD
#define HSL_SDA_Pin GPIO_PIN_2
#define HSL_SDA_GPIO_Port GPIOD
#define HSL_CLK_Pin GPIO_PIN_3
#define HSL_CLK_GPIO_Port GPIOD
#define TLY_SDA_Pin GPIO_PIN_0
#define TLY_SDA_GPIO_Port GPIOE
#define TLY_SCL_Pin GPIO_PIN_1
#define TLY_SCL_GPIO_Port GPIOE

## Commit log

2026-09-27 feat: 开源 TianXian 探险机器人（STM32F407 固件 + MaixCam 视觉 + 结构/PCB）
    - STM32F407ZGT6 HAL 固件：巡线/运动控制/任务编排/语音播报
    - MaixCam YOLOv5 五岳景点识别模型与部署脚本
    - SolidWorks 结构件与立创 EDA PCB 工程
    - README：架构说明、引脚分配、编译与部署流程、演示视频
    [xin升级版ccd.SLDPRT, xin电机低盘.SLDPRT, xin电机底盘上盖111.SLDPRT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]
2026-09-27 docs: README 增加整车实物图
2026-09-27 docs: 精简演示视频章节，移除 iframe 嵌入说明
2026-09-27 docs: 移除开源协议中的补充提示

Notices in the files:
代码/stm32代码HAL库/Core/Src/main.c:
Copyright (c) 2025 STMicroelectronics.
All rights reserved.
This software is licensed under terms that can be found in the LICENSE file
